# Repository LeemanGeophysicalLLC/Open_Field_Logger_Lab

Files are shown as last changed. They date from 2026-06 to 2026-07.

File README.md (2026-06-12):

# Open Field Logger Lab

**Open Field Logger Lab** is a low-cost educational data logger from
[Leeman Geophysical](https://leemangeophysical.com/) for learning basic field data logging with
0-5 V analog sensors.

It is designed for students to assemble, test, and use during field measurement projects for
our [GEARS workshops](https://leemangeophysicalllc.github.io/GEARS/) and to then have a useful
tool after the course. The goal is to teach practical instrumentation concepts without turning
the logger itself into the main project.

## Purpose

This project is intended to help students learn:

- through-hole soldering
- sensor wiring
- analog voltage measurement
- calibration
- sampling rate tradeoffs
- SD card data logging
- basic field deployment practices
- the effect of real-world conditions on measurements

The logger is intentionally simple, low-cost, and easy to modify.

## What this is not

Open Field Logger Lab is **not** a precision commercial data logger.
It is not intended for safety-critical measurements, unattended long-term monitoring,
harsh environmental deployment, or calibrated scientific measurements without
additional validation.

It is a teaching platform for learning how field logging works.

## Hardware overview

Rev A is built around:

- USB-C ESP32 DevKit-style microcontroller module
- ADS1115 16-bit ADC
- four nominal 0-5 V analog single ended inputs
- microSD card logging
- battery-backed real-time clock
- 9-18 VDC input power
- 5 V sensor power output
- simple status LEDs
- optional onboard NTC temperature divider

The analog inputs are intended for simple voltage-output sensors, signal conditioning circuits,
and student-built measurement experiments.

## Student assembly philosophy

Students solder only through-hole parts. Surface-mount parts are assembled before the
workshop for time concerns. We do, however, have a surface mount soldering challenge
for those that want to try SMT!

The through-hole assembly includes parts such as connectors, fuse clips, power components,
sockets, and selected educational components.

## Repository contents

Planned contents:

```text
hardware/      KiCad design files, schematics, PCB layout, fabrication outputs, BOM
firmware/      ESP32 firmware for logging and self-test
docs/          Datasheets and other relevant files as well as assembly instructions
examples/      Example CSV files and simple analysis notebooks/scripts

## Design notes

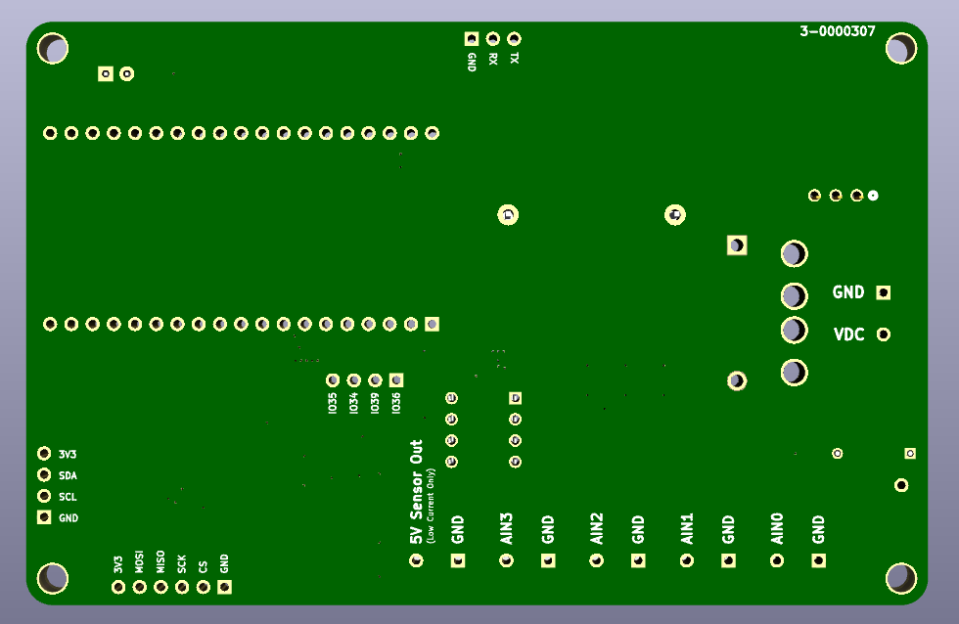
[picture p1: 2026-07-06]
hardware/Renders/pcb_back.png

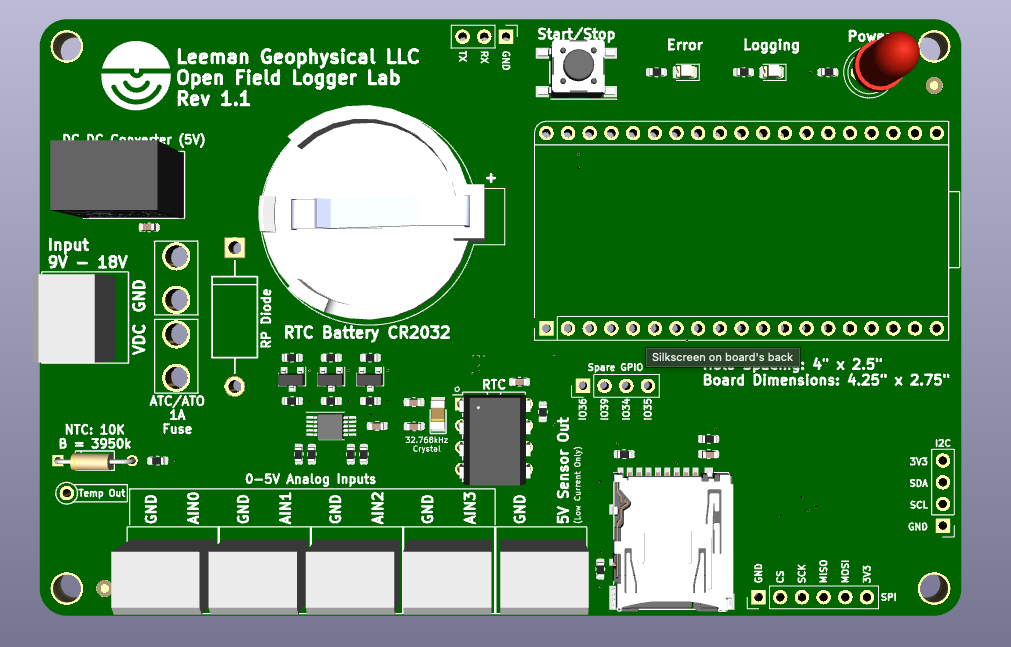
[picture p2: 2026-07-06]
hardware/Renders/pcb_front.png

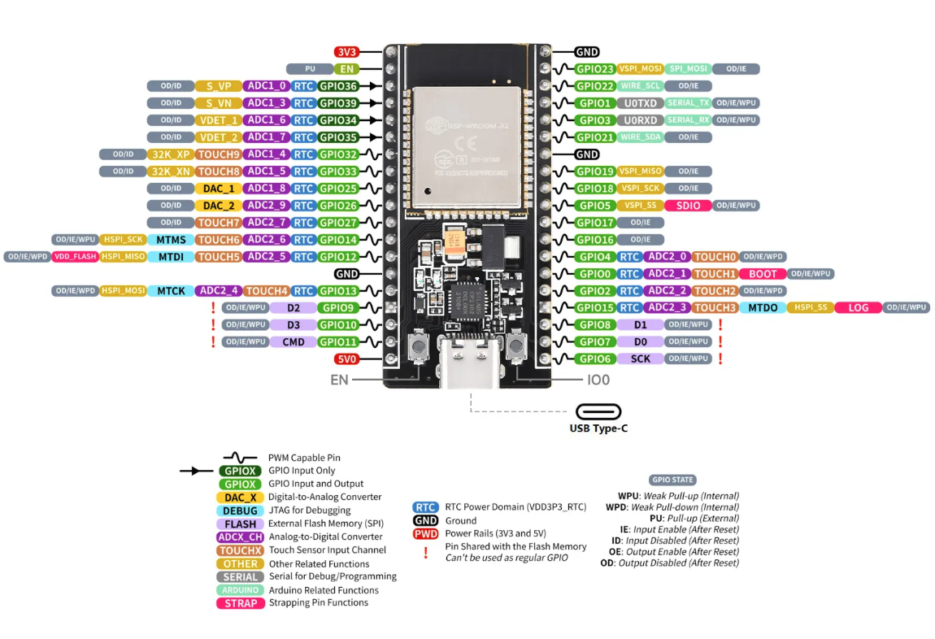
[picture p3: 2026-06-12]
docs/ESP_module_pinout.png

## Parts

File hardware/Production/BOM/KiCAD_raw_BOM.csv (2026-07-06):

Reference | Value | Internal Part Number | PValue | Populated
BT1 | 1-0000863 | 1-0000863 | CR2032 | 0
C1 | 1-0000019 | 1-0000019 | 4.7uF | 1
C2 | 1-0000007 | 1-0000007 | 0.1uF | 1
C3 | 1-0001902 | 1-0001902 | 7pF | 1
C4 | 1-0001902 | 1-0001902 | 7pF | 1
C5 | 1-0000007 | 1-0000007 | 0.1uF | 1
C6 | 1-0000007 | 1-0000007 | 0.1uF | 1
D1 | 1-0001188 | 1-0001188 | Green | 0
D2 | 1-0000599 | 1-0000599 | Blue | 1
D3 | 1-0001896 | 1-0001896 | 1N5822 | 0
D4 | 1-0000600 | 1-0000600 | Red | 1
FID1 | Fiducial_1mm_2mm | 0-0000000 | Fiducial | 0
FID2 | Fiducial_1mm_2mm | 0-0000000 | Fiducial | 0
H1 | Imperial4 | 0-0000000 | #4 | 0
H2 | Imperial4 | 0-0000000 | #4 | 0
H3 | Imperial4 | 0-0000000 | #4 | 0
H4 | Imperial4 | 0-0000000 | #4 | 0
J1 | 1-0001899 | 1-0001899 | 2 Pos | 0
J2 | 1-0001894 | 1-0001894 | 3522 | 0
J3 | 1-0001894 | 1-0001894 | 3522 | 0
J4 | AUX Input | 0-0000000 | AUX Input | 0
J5 | NP_Conn_01x03 | 0-0000000 | NP_Conn_01x03 | 0
J6 | NP_Conn_01x06 | 0-0000000 | 01x06 | 0
J7 | NP_Conn_01x04 | 0-0000000 | NP_Conn_01x04 | 0
J8 | 1-0000127 | 1-0000127 | microSD | 1
J9 | Conn_01x01
J10 | 1-0001899 | 1-0001899 | 2 Pos | 0
J11 | 1-0001899 | 1-0001899 | 2 Pos | 0
J12 | 1-0001899 | 1-0001899 | 2 Pos | 0
J13 | 1-0001899 | 1-0001899 | 2 Pos | 0
J14 | 1-0001899 | 1-0001899 | 2 Pos | 0
MI1 | 1-0001895 | 1-0001895 | 1A | 0
PCB1 | barepcb | 3-0000307 | Bare PCB | 1
Q1 | 1-0000163 | 1-0000163 | BSS138 | 1
Q2 | 1-0000163 | 1-0000163 | BSS138 | 1
Q3 | 1-0000163 | 1-0000163 | BSS138 | 1
R1 | 1-0000369 | 1-0000369 | 330 | 1
R2 | 1-0000008 | 1-0000008 | 150 | 1
R3 | 1-0000010 | 1-0000010 | 10k | 1
R4 | 1-0000008 | 1-0000008 | 150 | 1
R5 | 1-0000010 | 1-0000010 | 10k | 1
R6 | 1-0000010 | 1-0000010 | 10k | 1
R7 | 1-0000010 | 1-0000010 | 10k | 1
R8 | 1-0000010 | 1-0000010 | 10k | 1
R9 | 1-0000010 | 1-0000010 | 10k | 1
R10 | 1-0000010 | 1-0000010 | 10k | 1
R11 | 1-0000010 | 1-0000010 | 10k | 1
R12 | 1-0000174 | 1-0000174 | 100k | 1
R13 | 1-0000174 | 1-0000174 | 100k | 1
R14 | 1-0001184 | 1-0001184 | 10k | 1
R15 | 1-0000010 | 1-0000010 | 10k | 1
R16 | 1-0000010 | 1-0000010 | 10k | 1
R17 | 1-0000010 | 1-0000010 | 10k | 1
R18 | 1-0000010 | 1-0000010 | 10k | 1
SW1 | 1-0000681 | 1-0000681 | Red | 1
TH1 | 1-0001897 | 1-0001897 | NTC 10K | 0
U1 | 1-0001893 | 1-0001893 | RBT10W | 0
U2 | 1-0001890 | 1-0001890 | ESP32-DevKitC | 0
U3 | 1-0001892 | 1-0001892 | MCP7940 | 0
U4 | 1-0001891 | 1-0001891 | ADS1115 | 1
Y1 | 1-0001901 | 1-0001901 | 32.768kHz | 1

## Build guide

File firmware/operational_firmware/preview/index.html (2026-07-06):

DESKTOP PREVIEW — this page simulates the device; nothing here talks to real hardware

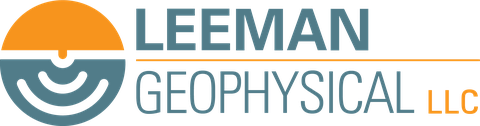
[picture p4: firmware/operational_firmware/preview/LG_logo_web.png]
Leeman Geophysical


OPEN FIELD LOGGER

IDLE

SD Card--

RTC--

Device Time--

Log File--

Achieved Rate--

Turn Off WiFi

Channel 1 (AIN0)

VOLTS

Channel 2 (AIN1)

VOLTS

Channel 3 (AIN2)

VOLTS

Channel 4 (AIN3)

VOLTS

## ADC & Logging Settings

ADC Input Range (PGA)

Data Rate (Hz)

Points To Average

## Set Clock (MCP7940 RTC)

Date & Time

Sync From Browser Clock Set Manual Time

## Firmware Update (OTA)

Running Version--

Only upload a .bin file built for this exact board. An incorrect or corrupt firmware file can leave the device unusable until it is reflashed over USB — double-check the file before uploading.

Upload And Restart

## SD Card Files

Refresh

File | Size
Loading...

## Last 2 Minutes

Channel 1 Channel 2 Channel 3 Channel 4

## Quick Start

1. Turn on WiFi | WiFi is off by default to save power. Double-click the physical Log button to turn it on — there is no timeout, so it stays on until you turn it off again (another double-click, or the "Turn Off WiFi" button on this page).
2. Connect | Join this device's WiFi network (shown as the device's SSID — printed to the serial console, and it's also the network name you'll see in your WiFi list once step 1 is done). No password is required. Then browse to http://192.168.4.1/ if the page doesn't open automatically.
3. Configure | Use the Configuration tab to set the ADC input range, data rate, and averaging before you start logging, and to set the clock.
4. Start/stop logging | Single-click the physical Log button on the board. This is the only way to start or stop logging — the web page cannot do it for you, so it always shows the true state of the device even if you're not looking at it when you click.
5. Watch it work | The Reading tab shows live voltages on all four channels at all times, whether or not logging is active. The Graph tab plots the last two minutes.
6. Get your data | Use the File Explorer tab to download (or delete) log files from the SD card. Files are named log001.txt, log002.txt, etc. — a new number every time you start a logging session.
7. Done for now? | Turn WiFi back off with another double-click, or press "Turn Off WiFi" at the top of this page, to save battery power. Logging keeps running either way — WiFi is only for watching/configuring.

## Choosing Data Rate & Averaging

Data Rate | How many logged rows per second you want (1, 2, 5, or 10 Hz).
Points To Average | How many raw ADC readings get combined into each logged row (1, 2, 4, 8, or 16). Higher averaging smooths out noise, but each extra reading takes real time on the chip.
Why they trade off | Every logged row requires reading all four channels, each averaged that many times, so a higher data rate and higher averaging together ask the ADC to do a lot more work per second. The ADS1115 can only convert so fast — a demanding combination like 10 Hz with 16x averaging may be more than it can keep up with.
What happens if it can't keep up | Nothing breaks. The firmware never blocks or errors over this — it just does its best and logs at whatever real rate results, and every row is timestamped with the actual time it was taken rather than the time you asked for.
How to check | Achieved Rate in the status strip at the top of every tab shows the real, measured logging rate while logging is active. Compare it to the Data Rate you selected.
If Achieved Rate is noticeably lower | Try reducing Points To Average first — it has the biggest effect on how much work each row takes. Reduce the Data Rate next if you still need it lower. Use higher averaging for slowly-changing signals where cleaner data matters more than speed, and lower averaging when you need to keep up with a fast-changing signal at the full rate you picked.

## LED Guide

At power-on | Both LEDs blink a few times together. This is just a self-test so you can see they both work — it doesn't mean anything is wrong.
Log LED, off | Not logging. The LED never blinks while idle, regardless of WiFi state — a unit sitting out in the field with logging stopped stays dark.
Log LED, 2 quick blinks (once) | WiFi was just turned on. A one-time acknowledgment right after a double-click (or nothing, if it happened while you were out of sight of the LED).
Log LED, 5 quick blinks (once) | WiFi was just turned off. Same idea, so you know the "Turn Off WiFi" button (or a double-click) actually took effect. Remember there's no auto-timeout, so this is the only confirmation you'll get.
Log LED, one quick pulse (~1.5s) | Logging, WiFi off. The normal state while actively recording data in the field.
Log LED, three quick pulses (~1.5s) | Logging, WiFi on. Both are active at once — fine to do, just remember WiFi has no auto-timeout and will stay on until you turn it off.
Error LED, on | Something needs attention: the RTC isn't running, the ADC wasn't detected, the SD card is missing (and logging was attempted), a write to the SD card failed, or all 999 log file numbers are already used. Check the status banner at the top of this page for the specific reason.

## Logged Data Format

Each log file is a plain CSV/text file: a header row, then one row per sample with the timestamp, the logger's uptime in milliseconds, and the four channel voltages — timestamp,uptime_ms,ch1_v,ch2_v,ch3_v,ch4_v. Open it in any spreadsheet or plotting tool.

## More Resources

Project Repository (GitHub) (https://github.com/LeemanGeophysicalLLC/Open_Field_Logger_Lab) Leeman Geophysical Website (https://leemangeophysical.com)

Leeman Geophysical LLC - Gentry, Arkansas, USA

## Preview Controls

None of this panel exists on the real device — it only exists here so you can exercise the page without hardware. In the field, the physical Log button single-click starts/stops logging and double-click toggles WiFi (with no dedicated on-page control for either, by design). The Reading/Graph values below are synthetic (sine waves + noise), not real ADC data.

Simulate Log Button Single-Click Simulate Log Button Double-Click Reset Preview State

Simulate SD card missing Simulate RTC fault Simulate 999 log files used

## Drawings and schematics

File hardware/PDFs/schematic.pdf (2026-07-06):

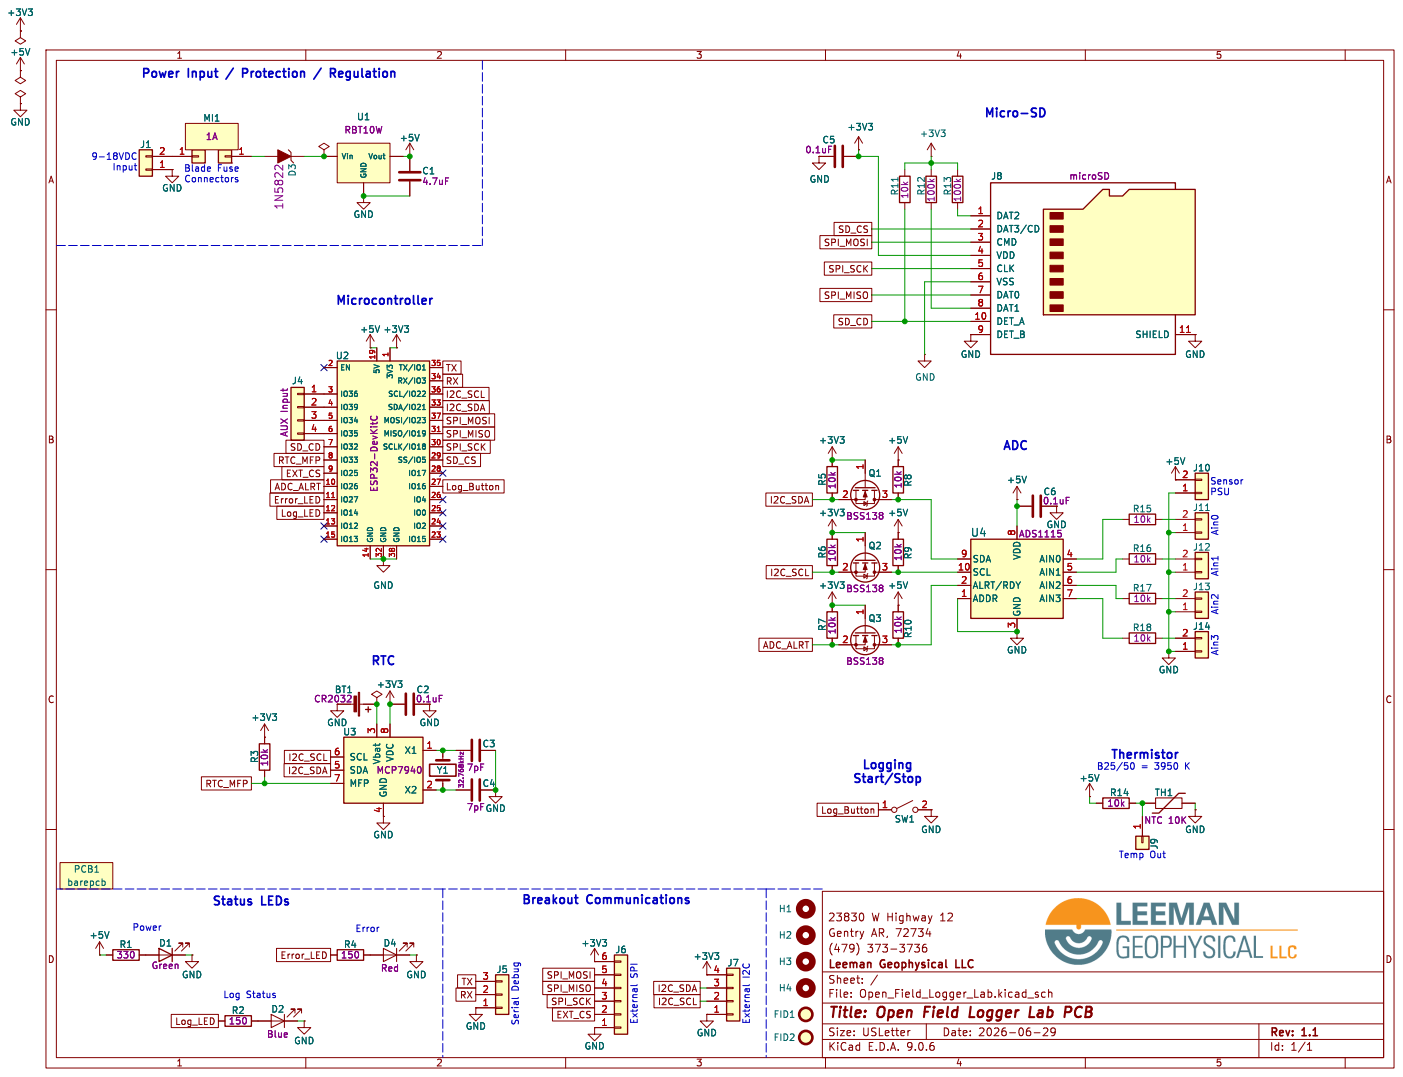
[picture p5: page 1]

Power Input / Protection / Regulation

Vin GND Vout GND

1 GND 38 TX/IO1 35 RX/IO3 34 SCL/IO22 36 SDA/IO21 33 MOSI/IO23 37 MISO/IO19 31 SCLK/IO18 30 SS/IO5 29

3 SDA 9 SCL 10 ALRT/RDY 2 ADDR 1 U4 ADS1115 GND

3 SDA 9 SCL 10 ALRT/RDY 2 ADDR 1

J14 GND GND GND GND

4 Vbat 3 SCL 6 SDA 5 MFP 7 U3 MCP7940 R18

4 Vbat 3 SCL 6 SDA 5 MFP 7 C4

(479) 373-3736 Gentry AR, 72734

E.D.A. 9.0.6 Size: USLetter Rev: 1.1 | D Date: 2026-06-29 KiCad

Id: 1/1 Title: Open Field Logger Lab PCB

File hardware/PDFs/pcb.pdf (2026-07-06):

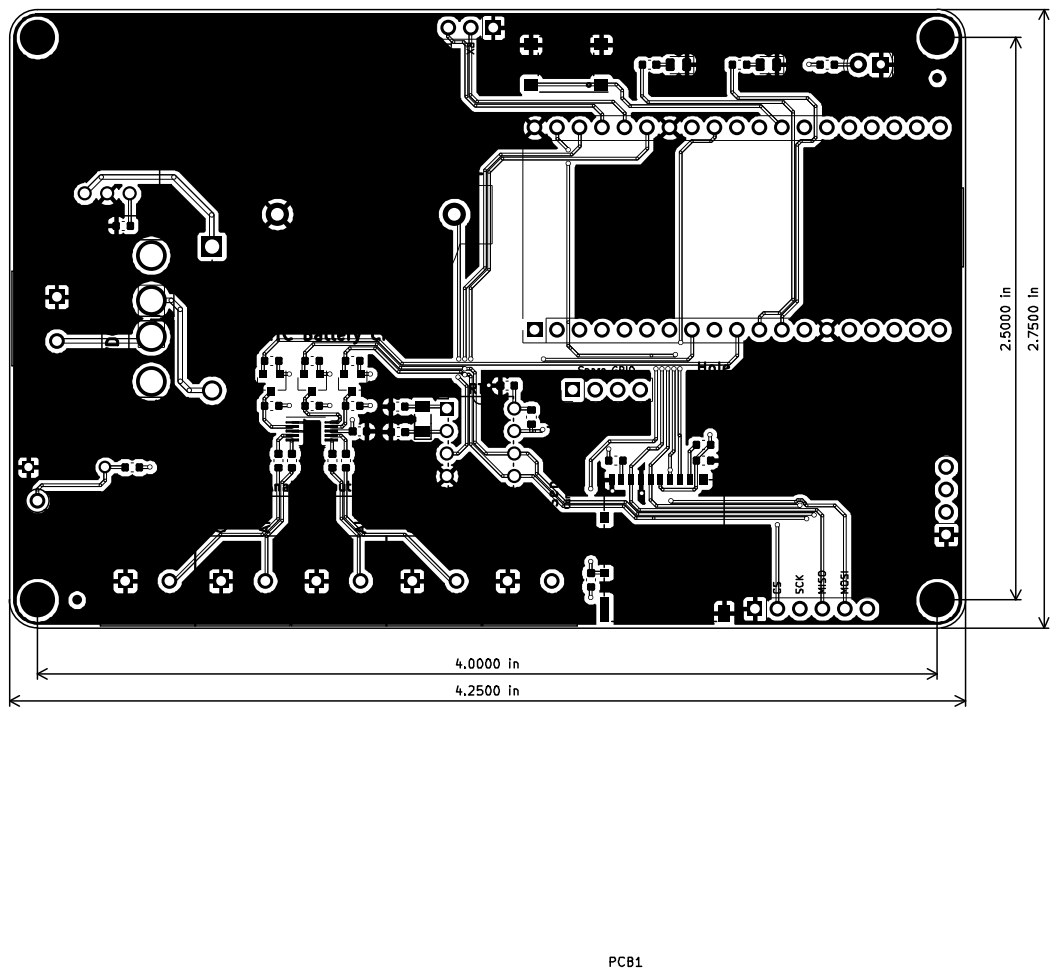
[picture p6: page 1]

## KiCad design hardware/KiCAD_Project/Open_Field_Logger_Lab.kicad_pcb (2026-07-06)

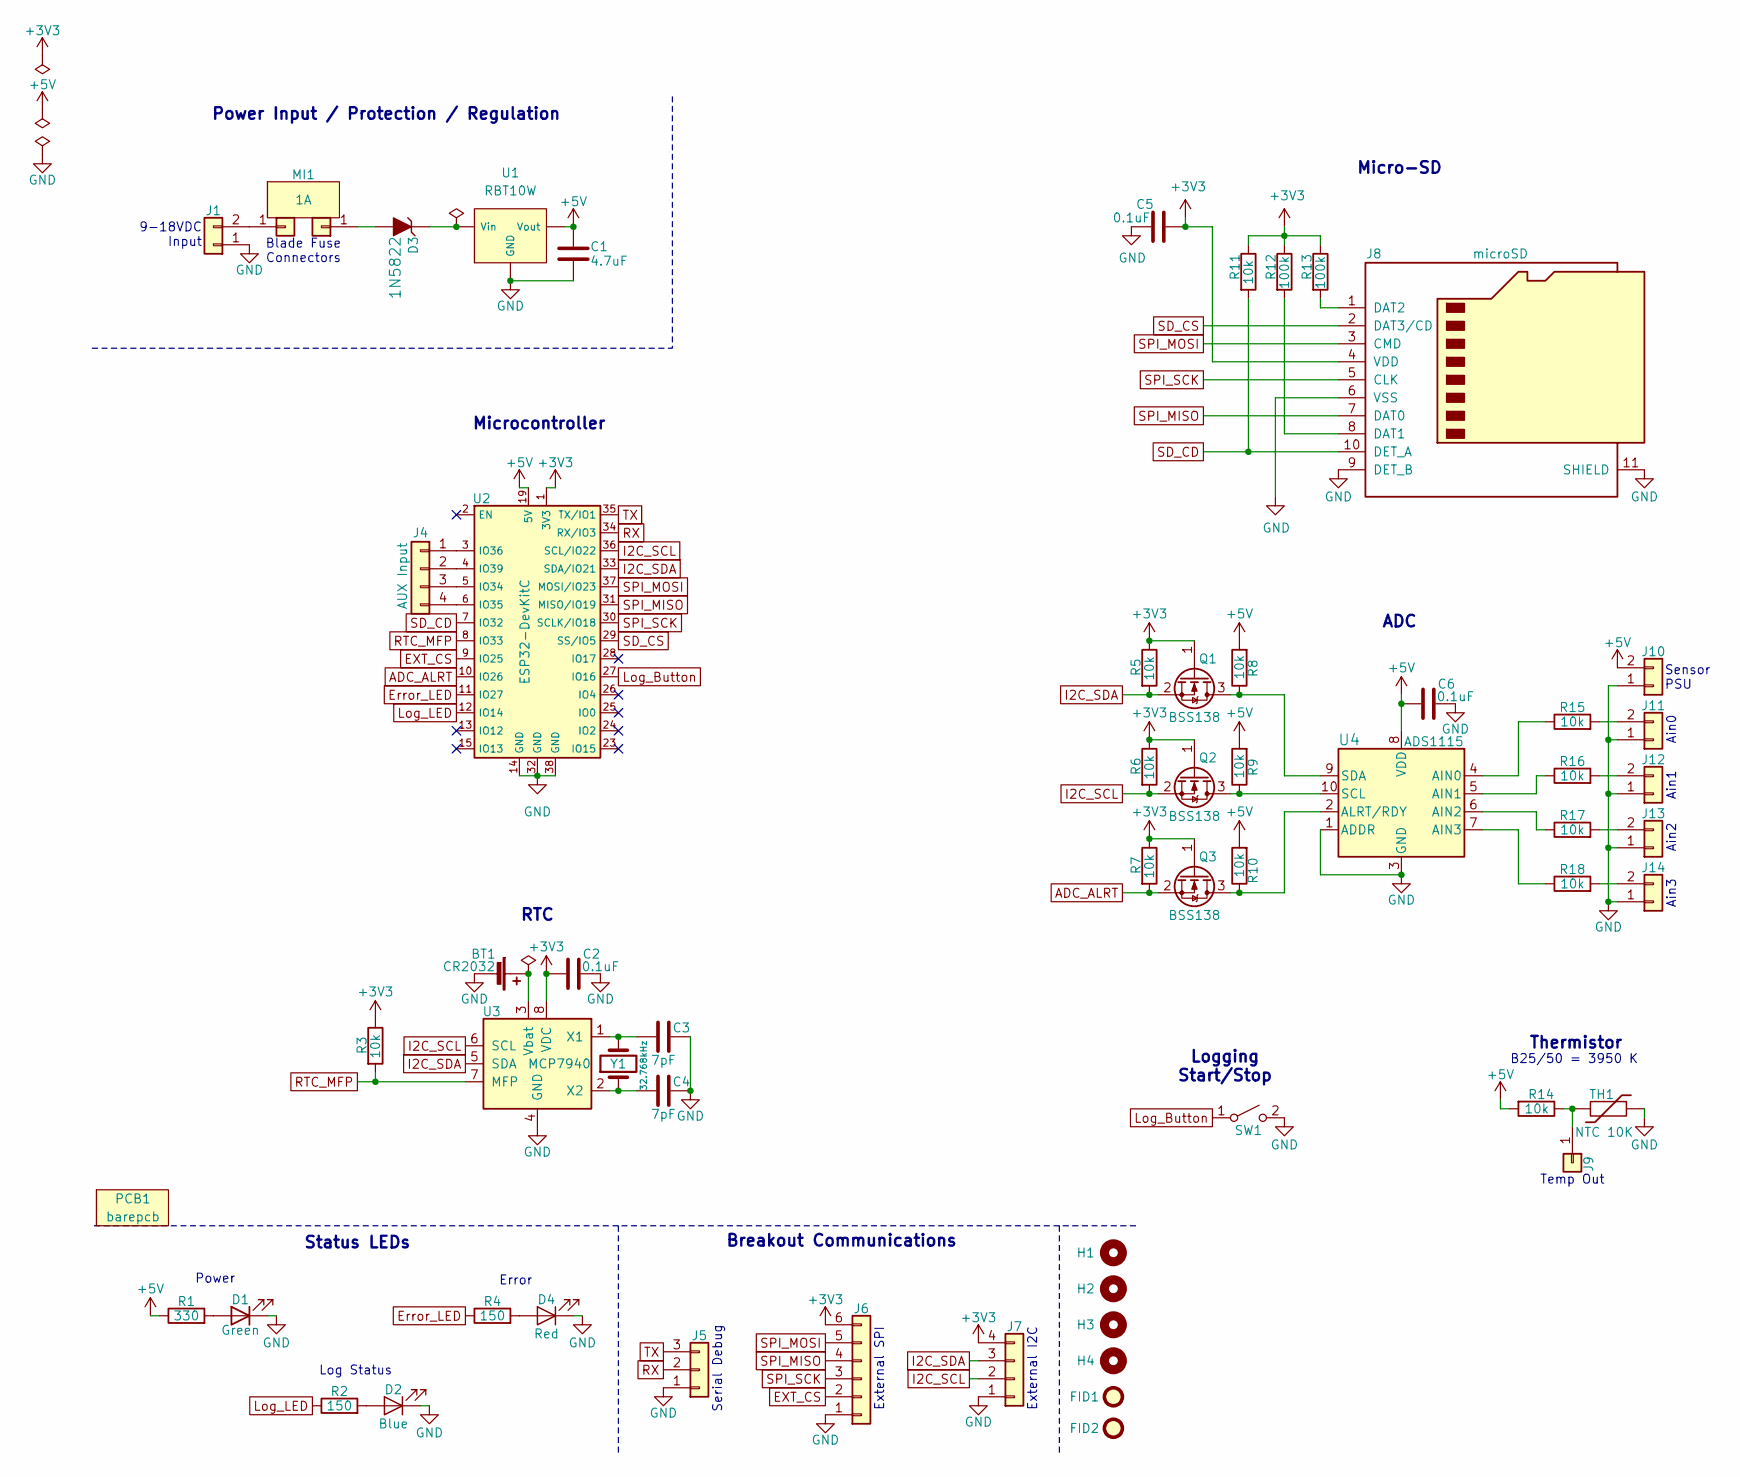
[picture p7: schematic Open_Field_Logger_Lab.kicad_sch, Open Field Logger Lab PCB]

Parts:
BT1: 1-0000863
C1: 1-0000019
C2, C5, C6: 1-0000007
C3, C4: 1-0001902
D1: 1-0001188
D2: 1-0000599
D3: 1-0001896
D4: 1-0000600
FID1, FID2: Fiducial_1mm_2mm; Fiducial_1mm_Mask2mm
H1, H2, H3, H4: Imperial4; MountingHole_imperial4
J1, J10, J11, J12, J13, J14: 1-0001899
J2, J3: 1-0001894
J4: AUX Input; PinHeader_1x04_P2.54mm_Vertical
J5: NP_Conn_01x03; PinHeader_1x03_P2.54mm_Vertical
J6: NP_Conn_01x06; PinHeader_1x06_P2.54mm_Vertical
J7: NP_Conn_01x04; PinHeader_1x04_P2.54mm_Vertical
J8: 1-0000127
J9: Conn_01x01; NP_Conn_ProtoPad
MI1: 1-0001895; misc_component
PCB1: barepcb
Q1, Q2, Q3: 1-0000163
R1: 1-0000369
R2, R4: 1-0000008
R3, R5, R6, R7, R8, R9, R10, R11, R15, R16, R17, R18: 1-0000010
R12, R13: 1-0000174
R14: 1-0001184
SW1: 1-0000681
TH1: 1-0001897
U1: 1-0001893
U2: 1-0001890
U3: 1-0001892
U4: 1-0001891
Y1: 1-0001901

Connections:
+3V3: C2.1, C5.2, J6.6, J7.4, J8.4 (VDD), Q1.1 (G), Q2.1 (G), Q3.1 (G), R3.1, R5.1, R6.1, R7.1, R11.1, R12.1, R13.1, U2.1 (3V3), U3.8 (VDC)
+5V: C1.1, C6.1, J10.2, R1.1, R8.2, R9.2, R10.2, R14.2, U1.3 (Vout), U2.19 (5V), U4.8 (VDD)
ADC_ALRT: Q3.2 (S), R7.2, U2.10 (IO26)
EXT_CS: J6.2, U2.9 (IO25)
Error_LED: R4.1, U2.11 (IO27)
GND: BT1.2 (-), C1.2, C2.2, C3.2, C4.2, C5.1, C6.2, D1.1 (K), D2.1 (K), D4.1 (K), J1.1, J5.1, J6.1, J7.1, J8.6 (VSS), J8.9 (DET_B), J8.11 (SHIELD), J10.1, J11.1, J12.1, J13.1, J14.1, SW1.2 (B), TH1.1, U1.2 (GND), U2.14 (GND), U2.32 (GND), U2.38 (GND), U3.4 (GND), U4.1 (ADDR), U4.3 (GND)
I2C_SCL: J7.2, Q2.2 (S), R6.2, U2.36 (SCL/IO22), U3.6 (SCL)
I2C_SDA: J7.3, Q1.2 (S), R5.2, U2.33 (SDA/IO21), U3.5 (SDA)
Log_Button: SW1.1 (A), U2.27 (IO16)
Log_LED: R2.1, U2.12 (IO14)
unnamed: BT1.1 (+), U3.3 (Vbat)
unnamed: D1.2 (A), R1.2
unnamed: D2.2 (A), R2.2
unnamed: D4.2 (A), R4.2
unnamed: J1.2, J2.1
unnamed: D3.2, J3.1
unnamed: J4.1, U2.3 (IO36)
unnamed: J4.2, U2.4 (IO39)
unnamed: J4.3, U2.5 (IO34)
unnamed: J4.4, U2.6 (IO35)
unnamed: J8.8 (DAT1), R12.2
unnamed: J8.1 (DAT2), R13.2
unnamed: J9.1, R14.1, TH1.2
unnamed: J11.2, R15.2
unnamed: J12.2, R16.2
unnamed: J13.2, R17.2
unnamed: J14.2, R18.2
unnamed: Q1.3 (D), R8.1, U4.9 (SDA)
unnamed: Q2.3 (D), R9.1, U4.10 (SCL)
unnamed: Q3.3 (D), R10.1, U4.2 (ALRT/RDY)
unnamed: D3.1, U1.1 (Vin)
unnamed: C3.1, U3.1 (X1), Y1.2
unnamed: C4.1, U3.2 (X2), Y1.1
unnamed: R15.1, U4.4 (AIN0)
unnamed: R16.1, U4.5 (AIN1)
unnamed: R17.1, U4.6 (AIN2)
unnamed: R18.1, U4.7 (AIN3)
RTC_MFP: R3.2, U2.8 (IO33), U3.7 (MFP)
RX: J5.2, U2.34 (RX/IO3)
SD_CD: J8.10 (DET_A), R11.2, U2.7 (IO32)
SD_CS: J8.2 (DAT3/CD), U2.29 (SS/IO5)
SPI_MISO: J6.4, J8.7 (DAT0), U2.31 (MISO/IO19)
SPI_MOSI: J6.5, J8.3 (CMD), U2.37 (MOSI/IO23)
SPI_SCK: J6.3, J8.5 (CLK), U2.30 (SCLK/IO18)
TX: J5.3, U2.35 (TX/IO1)

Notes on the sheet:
Temp Out
ADC
Sensor PSU
Power
Ain2
Ain0
Thermistor
B25/50 = 3950 K
RTC
Serial Debug
Ain1
Micro-SD
External I2C
Log Status
Microcontroller
Blade Fuse Connectors
Error
Logging Start/Stop
Ain3
Power Input / Protection / Regulation
Breakout Communications
Status LEDs
9-18VDC Input
External SPI

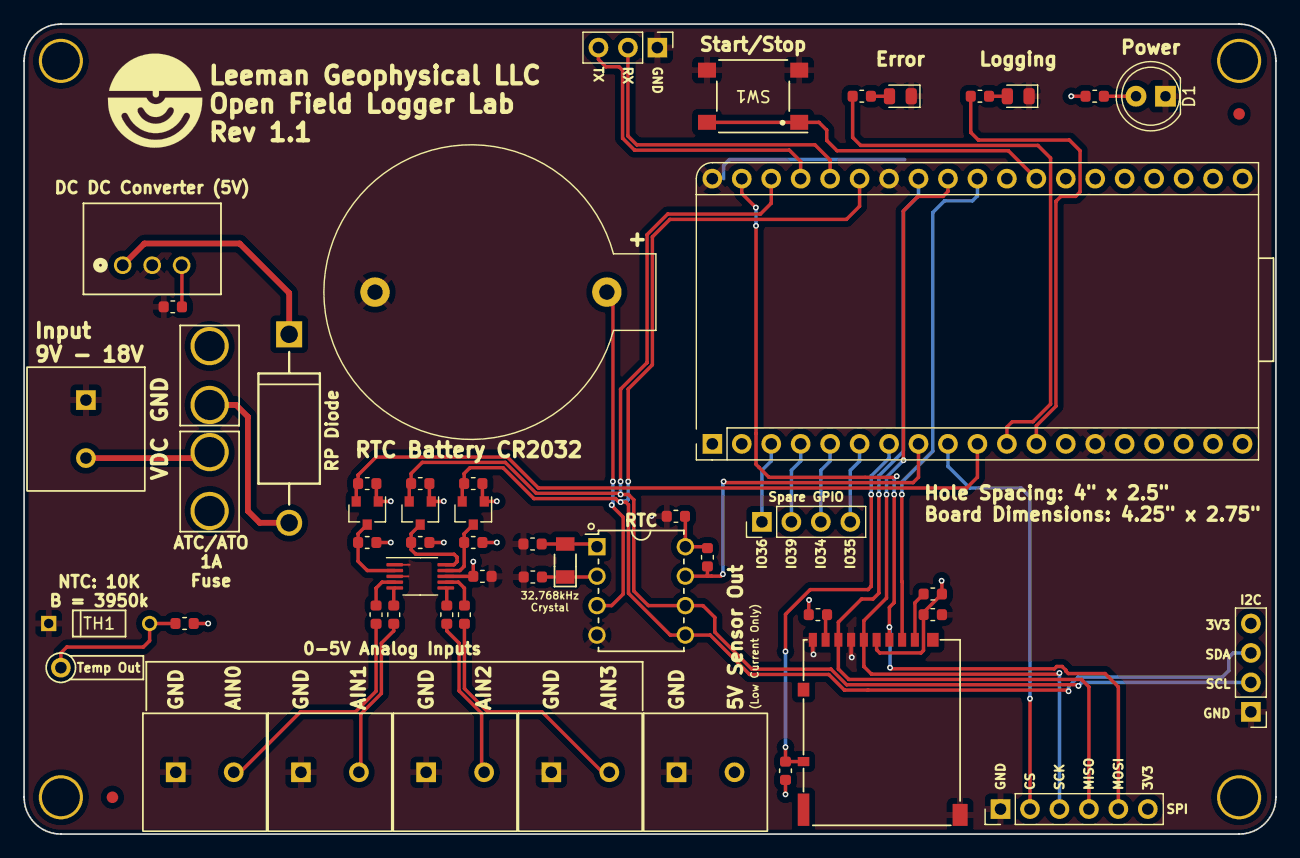
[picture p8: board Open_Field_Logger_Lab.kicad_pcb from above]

Board: 4 copper layers, 107.9 x 69.8 mm, 61 parts (0 on the bottom side), 45 nets.

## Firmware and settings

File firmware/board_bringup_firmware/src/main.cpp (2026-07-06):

/*
 * Open Field Logger Lab — Board Bring-Up Firmware
 *
 * Sequential self-test via serial at 115200 baud.
 * Press Enter before each test; type y/n for visual LED tests.
 * A PASS/FAIL summary table is printed at the end.
 *
 * Hardware (from schematic):
 *   Error LED    IO27  active HIGH
 *   Log LED      IO14  active HIGH
 *   Log Button   IO16  active LOW (INPUT_PULLUP)
 *   SD CS        IO5
 *   SD CD        IO32  LOW = card present
 *   ADS1115 ALRT IO26
 *   RTC MFP      IO33
 *   I2C SDA/SCL  IO21 / IO22
 *   SPI SCK/MISO/MOSI  IO18 / IO19 / IO23
 */

#include <Arduino.h>
#include <Wire.h>
#include <SPI.h>
#include <SD.h>
#include <Adafruit_ADS1X15.h>

// ---------------------------------------------------------------------------
// Pin assignments
// ---------------------------------------------------------------------------
static constexpr uint8_t PIN_ERROR_LED  = 27;
static constexpr uint8_t PIN_LOG_LED    = 14;
static constexpr uint8_t PIN_LOG_BUTTON = 16;
static constexpr uint8_t PIN_SD_CS      =  5;
static constexpr uint8_t PIN_SD_CD      = 32;

// I2C
static constexpr uint8_t PIN_I2C_SDA   = 21;
static constexpr uint8_t PIN_I2C_SCL   = 22;

// SPI (matches ESP32 VSPI defaults, stated explicitly for clarity)
static constexpr uint8_t PIN_SPI_SCK   = 18;
static constexpr uint8_t PIN_SPI_MISO  = 19;
static constexpr uint8_t PIN_SPI_MOSI  = 23;

// ---------------------------------------------------------------------------
// I2C addresses
// ---------------------------------------------------------------------------
static constexpr uint8_t ADS1115_ADDR  = 0x48;  // ADDR pin → GND
static constexpr uint8_t MCP7940_ADDR  = 0x6F;

// ---------------------------------------------------------------------------
// Test registry
// ---------------------------------------------------------------------------
static const char* TEST_NAMES[] = {
    "Error LED   (IO27)",
    "Log LED     (IO14)",
    "Log Button  (IO16)",
    "ADS1115 ADC (0x48)",
    "RTC MCP7940 (0x6F)",
    "SD Card     (IO5) "
};
static constexpr int NUM_TESTS = 6;
static bool g_results[NUM_TESTS];

// ---------------------------------------------------------------------------
// MCP7940 BCD helpers
// ---------------------------------------------------------------------------
static uint8_t toBCD(uint8_t v)   { return ((v / 10) << 4) | (v % 10); }
static uint8_t fromBCD(uint8_t b) { return ((b >> 4) & 0x0F) * 10 + (b & 0x0F); }

// ---------------------------------------------------------------------------
// Serial helpers
// ---------------------------------------------------------------------------
static void flushSerial() {
    delay(20);
    while (Serial.available()) Serial.read();
}

static void waitForEnter() {
    Serial.println(F("  [Press Enter to run this test]"));
    flushSerial();
    while (!Serial.available()) delay(10);
    flushSerial();
}

static char waitForYN() {
    flushSerial();
    char c = 0;
    while (c != 'y' && c != 'Y' && c != 'n' && c != 'N') {
        while (!Serial.available()) delay(10);
        c = Serial.read();
        flushSerial();
    }
    return c;
}

static void printHeader(int n) {
    Serial.println();
    Serial.print(F("--- TEST "));
    Serial.print(n + 1);
    Serial.print('/');
    Serial.print(NUM_TESTS);
    Serial.print(F(": "));
    Serial.println(TEST_NAMES[n]);
}

static void printResult(bool pass) {
    Serial.println(pass ? F("  >> PASS") : F("  >> FAIL"));
}

// ---------------------------------------------------------------------------
// Startup: print whatever the RTC currently holds
// ---------------------------------------------------------------------------
static void printRTCCurrentTime() {
    Wire.beginTransmission(MCP7940_ADDR);
    Wire.write(0x00);
    uint8_t err = Wire.endTransmission(false);
    if (err != 0 || Wire.requestFrom((uint8_t)MCP7940_ADDR, (uint8_t)7) < 7) {
        Serial.println(F("  RTC on startup: not reachable on I2C."));
        return;
    }

    uint8_t secRaw  = Wire.read();
    uint8_t minRaw  = Wire.read();
    uint8_t hourRaw = Wire.read();
    Wire.read();                        // weekday
    uint8_t dayRaw  = Wire.read();
    uint8_t monRaw  = Wire.read();
    uint8_t yearRaw = Wire.read();

    bool oscRunning = (secRaw & 0x80);  // ST bit set = oscillator enabled

    uint8_t sec  = fromBCD(secRaw  & 0x7F);
    uint8_t min  = fromBCD(minRaw);
    uint8_t hour = fromBCD(hourRaw & 0x3F);
    uint8_t day  = fromBCD(dayRaw);
    uint8_t mon  = fromBCD(monRaw  & 0x1F);
    uint8_t year = fromBCD(yearRaw);

    Serial.print(F("  RTC on startup: 20"));
    if (year < 10) Serial.print('0');
    Serial.print(year);
    Serial.print('-');
    if (mon  < 10) Serial.print('0');
    Serial.print(mon);
    Serial.print('-');
    if (day  < 10) Serial.print('0');
    Serial.print(day);
    Serial.print(' ');
    if (hour < 10) Serial.print('0');
    Serial.print(hour);
    Serial.print(':');
    if (min  < 10) Serial.print('0');
    Serial.print(min);
    Serial.print(':');
    if (sec  < 10) Serial.print('0');
    Serial.print(sec);
    Serial.println(oscRunning ? F("  (oscillator running)")
                              : F("  (oscillator stopped — fresh chip)"));
}

// ---------------------------------------------------------------------------
// TEST 1 — Error LED
// ---------------------------------------------------------------------------
static bool testErrorLED() {
    Serial.println(F("  Driving Error LED (IO27) HIGH."));
    digitalWrite(PIN_ERROR_LED, HIGH);
    Serial.println(F("  Is the red Error LED lit?  (y / n)"));
    char c = waitForYN();
    digitalWrite(PIN_ERROR_LED, LOW);
    return (c == 'y' || c == 'Y');
}

// ---------------------------------------------------------------------------
// TEST 2 — Log LED
// ---------------------------------------------------------------------------
static bool testLogLED() {
    Serial.println(F("  Driving Log LED (IO14) HIGH. Look for the BLUE led."));
    digitalWrite(PIN_LOG_LED, HIGH);
    Serial.println(F("  Is the blue Log LED lit?  (y / n)"));
    char c = waitForYN();
    digitalWrite(PIN_LOG_LED, LOW);
    return (c == 'y' || c == 'Y');
}

// ---------------------------------------------------------------------------
// TEST 3 — Log Button
// ---------------------------------------------------------------------------
static bool testLogButton() {
    Serial.println(F("  Press the Log Button (SW1) within 10 seconds..."));
    unsigned long deadline = millis() + 10000UL;

    while (millis() < deadline) {
        if (digitalRead(PIN_LOG_BUTTON) == LOW) {
            delay(20);  // debounce
            if (digitalRead(PIN_LOG_BUTTON) == LOW) {
                Serial.println(F("  Button press detected!"));
                while (digitalRead(PIN_LOG_BUTTON) == LOW) delay(10);
                return true;
            }
        }
    }
    Serial.println(F("  Timeout — no press detected."));
    return false;
}

// ---------------------------------------------------------------------------
// TEST 4 — ADS1115
// ---------------------------------------------------------------------------
static bool testADS1115() {
    Adafruit_ADS1115 ads;

    if (!ads.begin(ADS1115_ADDR, &Wire)) {
        Serial.println(F("  ERROR: ADS1115 not found at 0x48."));
        return false;
    }

    ads.setGain(GAIN_ONE);  // ±4.096 V full-scale, 0.125 mV/LSB
    Serial.println(F("  ADS1115 found. Single-ended readings (inputs may be floating):"));

    for (uint8_t ch = 0; ch < 4; ch++) {
        int16_t raw   = ads.readADC_SingleEnded(ch);
        float   volts = ads.computeVolts(raw);
        Serial.print(F("    AIN"));
        Serial.print(ch);
        Serial.print(F(": raw = "));
        Serial.print(raw);
        Serial.print(F(",  "));
        Serial.print(volts, 4);
        Serial.println(F(" V"));
    }
    return true;
}

// ---------------------------------------------------------------------------
// TEST 5 — RTC (MCP7940)
// ---------------------------------------------------------------------------
static bool testRTC() {
    // Parse compile-time stamp from preprocessor macros
    const char* months = "JanFebMarAprMayJunJulAugSepOctNovDec";
    char mon[4] = { __DATE__[0], __DATE__[1], __DATE__[2], '\0' };
    uint8_t compileMonth = 0;
    for (int i = 0; i < 12; i++) {
        if (strncmp(mon, months + i * 3, 3) == 0) { compileMonth = i + 1; break; }
    }
    uint8_t compileDay  = (uint8_t)atoi(__DATE__ + 4);
    uint8_t compileYear = (uint8_t)(atoi(__DATE__ + 7) - 2000);
    uint8_t compileHour = (uint8_t)atoi(__TIME__ + 0);
    uint8_t compileMin  = (uint8_t)atoi(__TIME__ + 3);
    uint8_t compileSec  = (uint8_t)atoi(__TIME__ + 6);

    Serial.print(F("  Compile time: 20"));
    if (compileYear < 10) Serial.print('0');
    Serial.print(compileYear);
    Serial.print('-');
    if (compileMonth < 10) Serial.print('0');
    Serial.print(compileMonth);
    Serial.print('-');
    if (compileDay < 10) Serial.print('0');
    Serial.print(compileDay);
    Serial.print(' ');
    if (compileHour < 10) Serial.print('0');
    Serial.print(compileHour);
    Serial.print(':');
    if (compileMin < 10) Serial.print('0');
    Serial.print(compileMin);
    Serial.print(':');
    if (compileSec < 10) Serial.print('0');
    Serial.println(compileSec);

    // Write to MCP7940 starting at register 0x00
    Wire.beginTransmission(MCP7940_ADDR);
    Wire.write(0x00);
    Wire.write(toBCD(compileSec) | 0x80);   // 0x00  seconds  | ST=1 (start osc)
    Wire.write(toBCD(compileMin));           // 0x01  minutes
    Wire.write(toBCD(compileHour));          // 0x02  hours (24 h, bit6=0)
    Wire.write(0x08);                        // 0x03  VBATEN=1 (bit3); day-of-week unused
    Wire.write(toBCD(compileDay));           // 0x04  date
    Wire.write(toBCD(compileMonth));         // 0x05  month
    Wire.write(toBCD(compileYear));          // 0x06  year
    uint8_t txErr = Wire.endTransmission();

    if (txErr != 0) {
        Serial.print(F("  ERROR: I2C write failed (err "));
        Serial.print(txErr);
        Serial.println(')');
        return false;
    }
    Serial.println(F("  RTC set. Waiting 2 s to verify it ticks..."));
    delay(2000);

    // Read back
    Wire.beginTransmission(MCP7940_ADDR);
    Wire.write(0x00);
    Wire.endTransmission(false);
    if (Wire.requestFrom((uint8_t)MCP7940_ADDR, (uint8_t)7) < 7) {
        Serial.println(F("  ERROR: Could not read RTC registers."));
        return false;
    }

    uint8_t secNow  = fromBCD(Wire.read() & 0x7F);   // mask ST bit
    uint8_t minNow  = fromBCD(Wire.read());
    uint8_t hourNow = fromBCD(Wire.read() & 0x3F);   // mask 12/24 bit
    Wire.read();                                       // weekday (unused)
    uint8_t dayNow  = fromBCD(Wire.read());
    uint8_t monNow  = fromBCD(Wire.read() & 0x1F);   // mask LPYR bit
    uint8_t yearNow = fromBCD(Wire.read());

    Serial.print(F("  RTC reads:     20"));
    if (yearNow < 10) Serial.print('0');
    Serial.print(yearNow);
    Serial.print('-');
    if (monNow < 10) Serial.print('0');
    Serial.print(monNow);
    Serial.print('-');
    if (dayNow < 10) Serial.print('0');
    Serial.print(dayNow);
    Serial.print(' ');
    if (hourNow < 10) Serial.print('0');
    Serial.print(hourNow);
    Serial.print(':');
    if (minNow < 10) Serial.print('0');
    Serial.print(minNow);
    Serial.print(':');
    if (secNow < 10) Serial.print('0');
    Serial.println(secNow);

    // Seconds should have advanced by ~2 (allow 1-5 for setup/flash variance)
    int delta = (int)secNow - (int)compileSec;
    if (delta < 0) delta += 60;  // handle minute rollover

    if (delta >= 1 && delta <= 5) {
        Serial.print(F("  Seconds advanced by "));
        Serial.print(delta);
        Serial.println(F(". RTC is running."));
        return true;
    }

    Serial.print(F("  ERROR: seconds delta = "));
    Serial.print(delta);
    Serial.println(F(" (expected 1-5). RTC may not be oscillating."));
    return false;
}

// ---------------------------------------------------------------------------
// TEST 6 — SD Card
// ---------------------------------------------------------------------------
static bool testSD() {
    bool cardPresent = (digitalRead(PIN_SD_CD) == LOW);
    Serial.print(F("  Card detect (IO32): "));
    if (!cardPresent) {
        Serial.println(F("no card present. Insert a FAT32 card and re-run."));
        return false;
    }
    Serial.println(F("card present."));

    // Explicit SPI pin assignment guards against featheresp32 variant remapping
    SPI.begin(PIN_SPI_SCK, PIN_SPI_MISO, PIN_SPI_MOSI, PIN_SD_CS);

    if (!SD.begin(PIN_SD_CS, SPI)) {
        Serial.println(F("  ERROR: SD.begin() failed. Check card (FAT32) and wiring."));
        return false;
    }

    uint8_t cardType = SD.cardType();
    Serial.print(F("  Card type: "));
    switch (cardType) {
        case CARD_MMC:  Serial.println(F("MMC"));     break;
        case CARD_SD:   Serial.println(F("SDSC"));    break;
        case CARD_SDHC: Serial.println(F("SDHC"));   break;
        default:        Serial.println(F("Unknown")); break;
    }
    Serial.print(F("  Card size: "));
    Serial.print((uint32_t)(SD.cardSize() / (1024 * 1024)));
    Serial.println(F(" MB"));

    // Write / read-back / verify
    static const char* path     = "/bringup.txt";
    static const char* testData = "Open Field Logger bring-up OK\n";

    SD.remove(path);
    File f = SD.open(path, FILE_WRITE);
    if (!f) {
        Serial.println(F("  ERROR: Could not open file for writing."));
        return false;
    }
    f.print(testData);
    f.close();
    Serial.println(F("  Write OK."));

    f = SD.open(path, FILE_READ);
    if (!f) {
        Serial.println(F("  ERROR: Could not open file for reading."));
        return false;
    }
    char buf[64] = {};
    int  i = 0;
    while (f.available() && i < (int)(sizeof(buf) - 1)) buf[i++] = (char)f.read();
    f.close();

    bool match = (strcmp(buf, testData) == 0);
    if (match) {
        Serial.println(F("  Read-back OK — contents match."));
    } else {
        Serial.print(F("  ERROR: content mismatch. Got: "));
        Serial.println(buf);
    }

    SD.remove(path);
    return match;
}

// ---------------------------------------------------------------------------
// setup / loop
// ---------------------------------------------------------------------------
void setup() {
    Serial.begin(115200);
    delay(500);  // allow USB-serial to enumerate

    // Pin modes
    pinMode(PIN_ERROR_LED,  OUTPUT);
    pinMode(PIN_LOG_LED,    OUTPUT);
    pinMode(PIN_LOG_BUTTON, INPUT_PULLUP);
    pinMode(PIN_SD_CD,      INPUT_PULLUP);

    digitalWrite(PIN_ERROR_LED, LOW);
    digitalWrite(PIN_LOG_LED,   LOW);

    Wire.begin(PIN_I2C_SDA, PIN_I2C_SCL);

    // Banner
    Serial.println(F("\r\n"));
    Serial.println(F("============================================="));
    Serial.println(F("  Open Field Logger — Board Bring-Up Test"));
    Serial.print  (F("  Built: "));
    Serial.print  (F(__DATE__));
    Serial.print  (F(" "));
    Serial.println(F(__TIME__));
    Serial.println(F("============================================="));
    Serial.println(F("  Press Enter before each test."));
    Serial.println(F("  LED tests: type  y  (pass) or  n  (fail)."));
    Serial.println(F("============================================="));
    printRTCCurrentTime();

    // Test dispatch table
    typedef bool (*TestFn)();
    static const TestFn testFns[NUM_TESTS] = {
        testErrorLED,
        testLogLED,
        testLogButton,
        testADS1115,
        testRTC,
        testSD
    };

    for (int i = 0; i < NUM_TESTS; i++) {
        printHeader(i);
        waitForEnter();
        g_results[i] = testFns[i]();
        printResult(g_results[i]);
    }

    // Summary table
    Serial.println(F("\r\n============================================="));
    Serial.println(F("  BRING-UP SUMMARY"));
    Serial.println(F("============================================="));

    bool allPass = true;
    for (int i = 0; i < NUM_TESTS; i++) {
        Serial.print(F("  "));
        Serial.print(TEST_NAMES[i]);
        Serial.println(g_results[i] ? F("  PASS") : F("  FAIL"));
        if (!g_results[i]) allPass = false;
    }

    Serial.println(F("============================================="));
    Serial.println(allPass ? F("  ALL TESTS PASSED") : F("  FAILURES DETECTED"));
    Serial.println(F("============================================="));

    // Hold result on LEDs
    digitalWrite(allPass ? PIN_LOG_LED : PIN_ERROR_LED, HIGH);
}

void loop() { /* complete after setup() */ }

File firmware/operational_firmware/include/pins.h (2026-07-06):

#pragma once

// Open Field Logger Lab — hardware pin map.
//
// Copied from the schematic-derived table in
// firmware/board_bringup_firmware/CLAUDE.md so both firmwares agree on the
// same wiring. If the schematic ever changes, update both places.

#include <stdint.h>

// Status LEDs / button
static constexpr uint8_t PIN_ERROR_LED  = 27;  // active HIGH
static constexpr uint8_t PIN_LOG_LED    = 14;  // active HIGH
static constexpr uint8_t PIN_LOG_BUTTON = 16;  // active LOW, INPUT_PULLUP

// I2C bus (shared by the ADS1115 ADC and the MCP7940 RTC)
static constexpr uint8_t PIN_I2C_SDA = 21;
static constexpr uint8_t PIN_I2C_SCL = 22;

// SPI bus (SD card)
static constexpr uint8_t PIN_SPI_SCK  = 18;
static constexpr uint8_t PIN_SPI_MISO = 19;
static constexpr uint8_t PIN_SPI_MOSI = 23;
static constexpr uint8_t PIN_SD_CS    = 5;
static constexpr uint8_t PIN_SD_CD    = 32;  // LOW = card present

// I2C peripheral addresses
static constexpr uint8_t ADS1115_I2C_ADDR = 0x48;  // ADDR pin tied to GND
static constexpr uint8_t MCP7940_I2C_ADDR = 0x6F;

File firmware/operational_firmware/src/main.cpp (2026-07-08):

/*
 * Open Field Logger Lab — Operational Firmware
 *
 * Continuously samples the four ADS1115 single-ended inputs, logs them to
 * sequentially-numbered SD card files (log001.txt, log002.txt, ...) with an
 * MCP7940 RTC timestamp, and hosts a small local web page over its own WiFi
 * access point (Configuration / Reading / File Explorer / Graph / Help
 * tabs) so students can watch and configure the logger from a laptop or
 * phone.
 *
 * This file is intentionally thin: it just wires the modules in lib/
 * together and runs the main loop. Read the header comment at the top of
 * each module (UiIo, Mcp7940Rtc, AdcManager, SamplingEngine, SdLogger,
 * SdFiles, SettingsStore, WebPortal) to see how each peripheral is used —
 * that's where the actual explanation of *how* lives.
 *
 * Hardware control summary:
 *   - The physical Log Button carries two gestures. A single click starts
 *     or stops logging — the web page mirrors that state but can never
 *     change it. A double click toggles the WiFi access point on/off.
 *   - WiFi starts OFF at boot to save power in the field, with no
 *     auto-timeout once turned on — a student double-clicks to bring it up,
 *     and turns it back off with a second double-click or the page's own
 *     "Turn Off WiFi" button. (Since WiFi is off by default, a printed
 *     label on the enclosure describing the double-click gesture is worth
 *     having — a brand new board can't show its own instructions until
 *     WiFi is already on.)
 *   - Both LEDs blink a few times at boot as a quick self-test. After that
 *     the Log LED never blinks while idle (regardless of WiFi state) — it
 *     only blinks while logging: one quick pulse every 1.5s with WiFi off,
 *     or three quick pulses every 1.5s with WiFi on. Separately, turning
 *     WiFi on/off gets its own one-time acknowledgment blink (2 blinks for
 *     on, 5 for off) regardless of whether logging is active, so a student
 *     gets instant feedback that their double-click registered.
 *   - The Error LED lights for: RTC not running, ADC not detected, the SD
 *     card missing when a log-start was attempted, an SD write failure, or
 *     all 999 sequential log numbers already being used.
 *   - The ADC free-runs continuously (Reading/Graph tabs are always live)
 *     regardless of logging state; only the SD-append step is gated on it.
 *   - Bluetooth is released and never used, and the CPU runs at a reduced
 *     160 MHz — both purely to cut power draw for battery-powered field use.
 */

#include <Arduino.h>
#include <WiFi.h>
#include <Wire.h>
#include <esp_bt.h>
#include <string.h>

#include "AdcManager.h"
#include "Mcp7940Rtc.h"
#include "SamplingEngine.h"
#include "SdFiles.h"
#include "SdLogger.h"
#include "SettingsStore.h"
#include "UiIo.h"
#include "WebPortal.h"
#include "logger_types.h"
#include "pins.h"

namespace {

UiIo g_ui;
Mcp7940Rtc g_rtc;
AdcManager g_adc;
SdLogger g_sdlog;
SamplingEngine g_engine;

LoggerSettings g_settings;
bool g_adc_detected = false;

// ---------------------------------------------------------------------------
// WebPortalHooks implementations — the only place the web layer's function
// pointers touch the actual application state.
// ---------------------------------------------------------------------------

void hookGetSettings(LoggerSettings &out) { out = g_settings; }

bool hookApplySettings(const LoggerSettings &in, char *err, size_t err_len) {
  (void)err;
  (void)err_len;
  g_settings = in;
  if (g_adc_detected) {
    g_adc.setGain(g_settings.adc_gain);
  }
  g_engine.configure(g_settings.sample_rate_hz, g_settings.averages_per_sample);
  settingsSave(g_settings);  // best-effort; a flash write failure doesn't undo the live change
  return true;
}

void hookGetStatus(LiveStatus &out) {
  out.logging_active = g_engine.isLoggingActive();
  strlcpy(out.current_log_file, g_sdlog.currentLogFileName(), sizeof(out.current_log_file));
  out.sd_ok = g_sdlog.isReady();
  out.sd_card_present = g_sdlog.isCardPresent();
  out.rtc_ok = g_rtc.isRunning();

  const bool board_fault = !out.rtc_ok || !g_adc_detected;
  out.error_active = board_fault || g_sdlog.hasError();
  if (g_sdlog.hasError()) {
    strlcpy(out.error_reason, g_sdlog.errorReason(), sizeof(out.error_reason));
  } else if (!g_adc_detected) {
    strlcpy(out.error_reason, "ADS1115 not detected", sizeof(out.error_reason));
  } else if (!out.rtc_ok) {
    strlcpy(out.error_reason, "RTC not running", sizeof(out.error_reason));
  } else {
    out.error_reason[0] = '\0';
  }

  RtcDateTime dt;
  if (g_rtc.now(dt)) {
    Mcp7940Rtc::formatTimestamp(dt, out.rtc_time_str, sizeof(out.rtc_time_str));
  } else {
    strlcpy(out.rtc_time_str, "--", sizeof(out.rtc_time_str));
  }

  out.uptime_ms = millis();
  out.samples_logged = g_sdlog.samplesLoggedThisSession();
  out.achieved_sample_hz = g_engine.getAchievedSampleHz();
}

void hookGetReading(ChannelSample &out, uint32_t &uptime_ms, bool &logging_active) {
  out = g_engine.getLatestReading();
  uptime_ms = millis();
  logging_active = g_engine.isLoggingActive();
}

bool hookSyncRtc(const RtcDateTime &dt, char *err, size_t err_len) {
  if (!g_rtc.setDateTime(dt)) {
    snprintf(err, err_len, "RTC write failed");
    return false;
  }
  return true;
}

bool hookDeleteFile(const char *name, char *err, size_t err_len) {
  const bool is_active =
      g_engine.isLoggingActive() && strcmp(name, g_sdlog.currentLogFileName()) == 0;
  if (is_active) {
    snprintf(err, err_len, "cannot delete the active log file while logging");
    return false;
  }
  if (!deleteFile(name, false)) {
    snprintf(err, err_len, "file not found or could not be deleted");
    return false;
  }
  return true;
}

// Fires once from webPortalSetWifiOn() whenever WiFi actually changes
// state, whichever gesture triggered it (button double-click or the page's
// "Turn Off WiFi" button) — 2 quick blinks for on, 5 for off.
void hookOnWifiChanged(bool now_on) { g_ui.wifiChangeBlink(now_on ? 2 : 5); }

// Builds a unique SSID from the ESP32's own MAC address, e.g.
// "OpenFieldLogger-A1B2C3" — guarantees every one of the ~20 units in a
// classroom gets a distinct network with zero manual setup.
void buildSsid(char *out, size_t out_len) {
  uint8_t mac[6] = {0};
  WiFi.macAddress(mac);
  snprintf(out, out_len, "OpenFieldLogger-%02X%02X%02X", mac[3], mac[4], mac[5]);
}
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

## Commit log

2026-06-15 Initial PCB Layout
    [Open_Field_Logger_Lab.kicad_pcb]
2026-06-15 Updated PCB title block, Added PCB# silk
    [Open_Field_Logger_Lab.kicad_pcb]
2026-06-16 Rev 1.0 production files
    [KiCAD_raw_BOM.csv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]
2026-06-29 Fixed Issues: #2 #3 #4
    [Open_Field_Logger_Lab.kicad_pcb, Open_Field_Logger_Lab.kicad_sch]
2026-06-30 Issue Revision: #6
    [Open_Field_Logger_Lab.kicad_pcb, Open_Field_Logger_Lab.kicad_sch]
2026-07-06 Update production files to Rev 1.1
    [KiCAD_raw_BOM.csv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]
2026-07-08 Rev 1.1 PCB production files
    [Open_Field_Logger_Lab-B_Cu.gbr, Open_Field_Logger_Lab-B_Mask.gbr, Open_Field_Logger_Lab-B_Paste.gbr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]
